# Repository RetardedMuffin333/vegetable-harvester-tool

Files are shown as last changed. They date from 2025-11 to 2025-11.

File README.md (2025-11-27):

# Robotic Tool for Harvesting Stem Vegetables
Electromechanical end-effector tool for gripping and cutting stem vegetables (such as asparagus).  
Designed to be mounted on a delta robot for automated harvesting.

This project was created as part of the **Electro-Mechanical Product Design** course at the University of Ljubljana, Faculty of Electrical Engineering.

The repository includes a complete **mechanical design**, **electronics design**, and **system integration** of the end-effector.

---

## 1. Project Overview

The goal of this project was to design an end-effector capable of:

- Gripping a single stem vegetable from any direction  
- Stabilizing it during cutting  
- Cutting it in a horizontal plane  
- Attaching to a delta parallel robot  
- Staying within strict weight and size limits  

The final design includes a fully developed mechanical concept and a matching custom PCB designed for motor control and system interfacing.

---

## 2. Mechanical Design

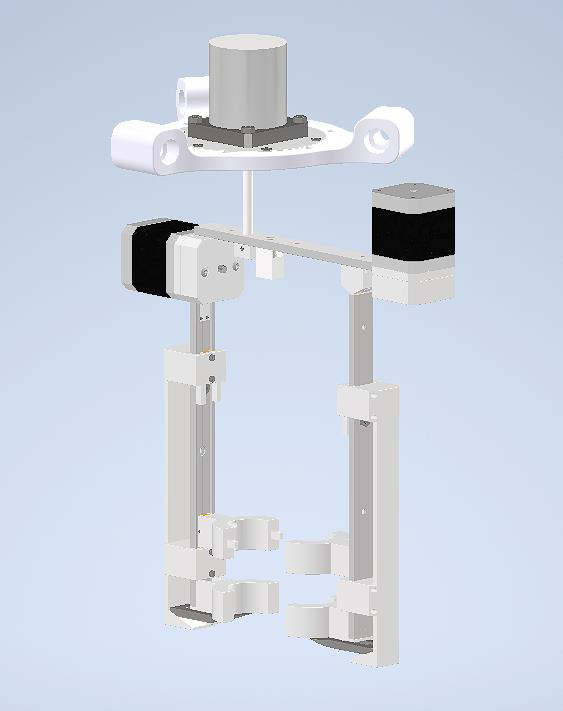
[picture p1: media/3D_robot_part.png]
Mechanical overview


### Key Features
- Four-arm cage gripping mechanism  
- Two fixed arms + two moving arms  
- Belt-driven horizontal and vertical motion  
- Height-triggered cutting mechanism (cams, ramps, springs, sliding blade)  
- Servo motor allowing 360° rotation  
- Designed to avoid unripe vegetables  
- Target mass: **< 700 g**

### Included Files
- Complete 3D CAD model (assemblies and components)  
- Exploded view  
- Mechanism simulation  
- Technical drawings  
- Bill of materials  

All mechanical files are located in:  
`/mechanical/`

---

## 3. Electronics Design

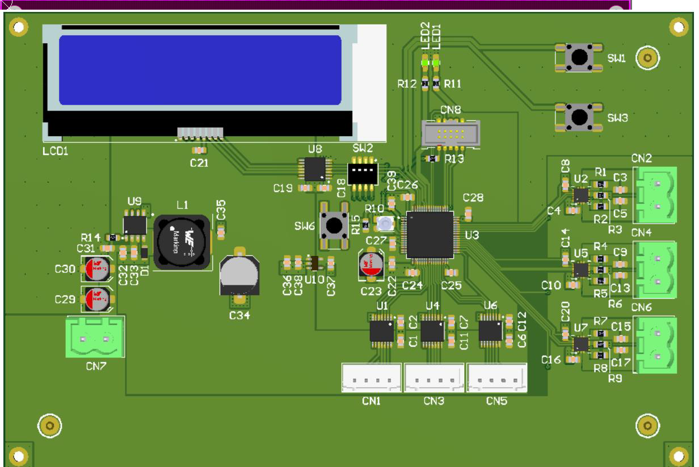
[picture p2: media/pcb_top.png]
PCB top view


### Key Features
- STM32L476RG microcontroller  
- Three MP6619 H-bridge motor drivers  
- 24 V → 5 V DC/DC switching regulator  
- 5 V → 3.3 V linear regulator  
- Level shifter for encoder inputs  
- JTAG programming header  
- Status LEDs, DIP switches, potentiometer, push buttons  
- LCD display interface  
- Custom 2-layer PCB designed in Altium

### Included Files
- Full schematics  
- PCB layout  
- 3D PCB assembly  
- Gerber files  
- Custom component libraries

All electronics files are located in:  
`/electronics/`

---

## 4. Firmware

### Overview
The firmware folder contains **prototype firmware** for the vegetable-harvester end-effector tool.  
The goal of this code is to document and simulate the intended behaviour of the tool without requiring access to the real robot or STM32 hardware.

### Key Features
- Hardware-agnostic state machine architecture  
- PC-friendly stub implementation for testing  
- No external dependencies — pure C11  
- Allows validation of logic and behaviour on any PC  

### Files
- **`tool_controller.c`** — High-level state machine controlling the harvester tool:
  - Opens/closes gripper  
  - Lowers/raises tool  
  - Manages cutting height  
  - Handles emergency-stop  
  - Uses abstract `hw_*` hardware calls (fully hardware-agnostic)  

- **`hw_stub.c`** — PC-friendly stub implementation of the hardware layer:
  - Replaces real STM32 GPIO/PWM/UART with `printf()` simulations  
  - Allows running the full tool cycle on any PC  
  - Useful for validating logic and behaviour  

### Compile & Run (Optional)
```bash
gcc tool_controller.c hw_stub.c -std=c11 -Wall -Wextra -o harvester_test
./harvester_test
```

All firmware files are located in:  
`/firmware/`

---

## 6. Media

Images, renders, videos, mechanism animations, exploded views, and PCB 3D previews.

Stored in:  
`/media/`

---

## 7. Documentation

- Mechanical report (PDF)  
- Electronics report (PDF)  
- Technical drawings (PDF)

Located in:  
`/docs/`

---

## 8. Skills Demonstrated

### Mechanical Engineering
- CAD modeling and assemblies  
- Motion systems and kinematics  
- Mechanism and tool design  
- Component selection  
- Design for constraints (weight, geometry, material limits)

### Electrical Engineering
- Schematic design in Altium  
- PCB layout (routing, grounding, decoupling)  
- Motor driver circuitry  
- Power conversion (DC/DC and LDO)  
- Digital/analog interfacing  

### Systems Engineering
- Integrating mechanical and electronic subsystems  
- Error analysis and optimization  
- Documenting design workflows  
- Understanding system constraints and interactions

---

## 9. Future Improvements

- Reduce overall mass of the tool  
- Optimize motor selection and torque requirements  
- Improve PCB thermal performance  
- Add environmental and proximity sensors  
- Add end-stop switches for better motor homing  
- Integrate a small UPS to preserve state on power loss  

---

## 10. Repository Structure

```
vegetable-harvester-tool/
│
├── mechanical/
├── electronics/
├── firmware/
├── media/
├── docs/
└── README.md
```

---

## 11. Author

**Aljaž Murovec**  
University of Ljubljana — Faculty of Electrical Engineering

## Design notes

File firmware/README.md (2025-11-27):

# Firmware (Prototype)

This folder contains the **prototype firmware** for the vegetable-harvester end-effector tool.  
The goal of this code is to document and simulate the intended behaviour of the tool without requiring access to the real robot or STM32 hardware.

---

## Files

### `tool_controller.c`
High-level state machine controlling the harvester tool:

- Opens gripper  
- Closes gripper  
- Lowers tool to cutting height  
- Raises tool  
- Releases harvested vegetable  
- Monitors emergency-stop  
- Uses abstract `hw_*` hardware calls (no MCU-specific code inside)

The code is fully hardware-agnostic.  
All physical interactions are delegated to the hardware layer.

---

### `hw_stub.c`
A **PC-friendly stub** implementation of the hardware layer.

- Replaces real STM32 GPIO/PWM/UART with `printf()` simulations  
- Allows running the full tool cycle on any PC  
- Useful for validating logic and behaviour  
- No external dependencies — pure C11

Compile & run locally (optional):

```bash
gcc tool_controller.c hw_stub.c -std=c11 -Wall -Wextra -o harvester_test
./harvester_test

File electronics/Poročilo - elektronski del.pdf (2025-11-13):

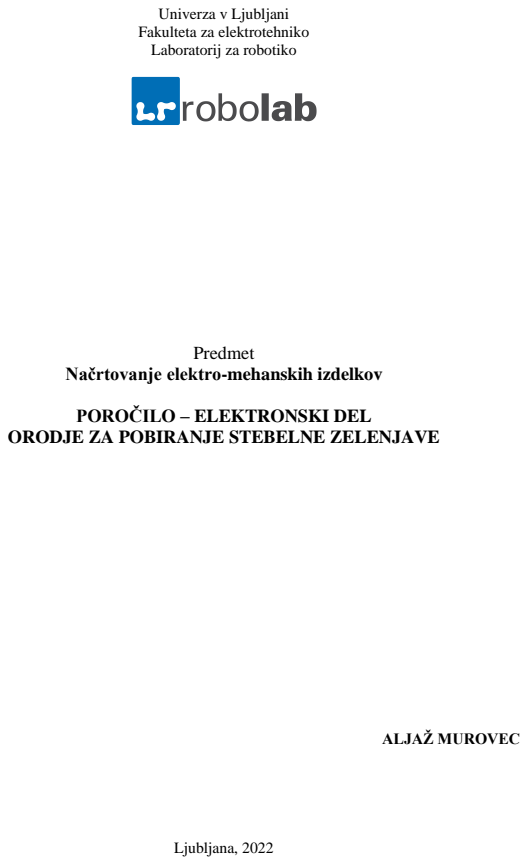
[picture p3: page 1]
Predmet; ALJAŽ MUROVEC; Ljubljana, 2022

Univerza v Ljubljani
Fakulteta za elektrotehniko
Laboratorij za robotiko

Načrtovanje elektro-mehanskih izdelkov

POROČILO – ELEKTRONSKI DEL

ORODJE ZA POBIRANJE STEBELNE ZELENJAVE

# 1.) Predstavitev problema in ideje

Izdelava načrta električnega vezja oz. PCB plošče, ki bo omogočala realizacijo delovanja mehanskega dela pri načrtovanju orodja za pobiranje stebelne zelenjave. Kot osnovo vezja smo vzeli mikrokrmilnik STM32L476RG na katerega je bilo potrebno pripeljati vse ostale komponente, ki bodo skrbele za pravilno delovanje orodja. Za napajanje vezja skrbi 24V baterija, zato je bilo potrebno to napetost zmanjšati, saj določene komponente vezja delujejo na precej manjši napetosti, poleg tega pa poskrbeti tudi za stabilizacijo napetosti. Večji del vezja vsebuje elemente, potrebne za delovanje oz. krmiljenje motorjev, saj ti opravljajo glavno funkcijo orodja. Za to sem potreboval h-mostiče in enkoderje, nato pa sem poleg močnostnih konektorjev in statusnih LED diod, za boljšo uporabniško izkušnjo dodal še LCD zaslon, na kateremu se izpisujejo različne informacije. Za pravilno delovanje vezja je bilo potrebno poskrbeti še za pravilno širino povezav oz. upoštevati tokovne zahteve vezja.

# 2.) Predstavitev elektronskega dela

## 2.1.) Kosovnica

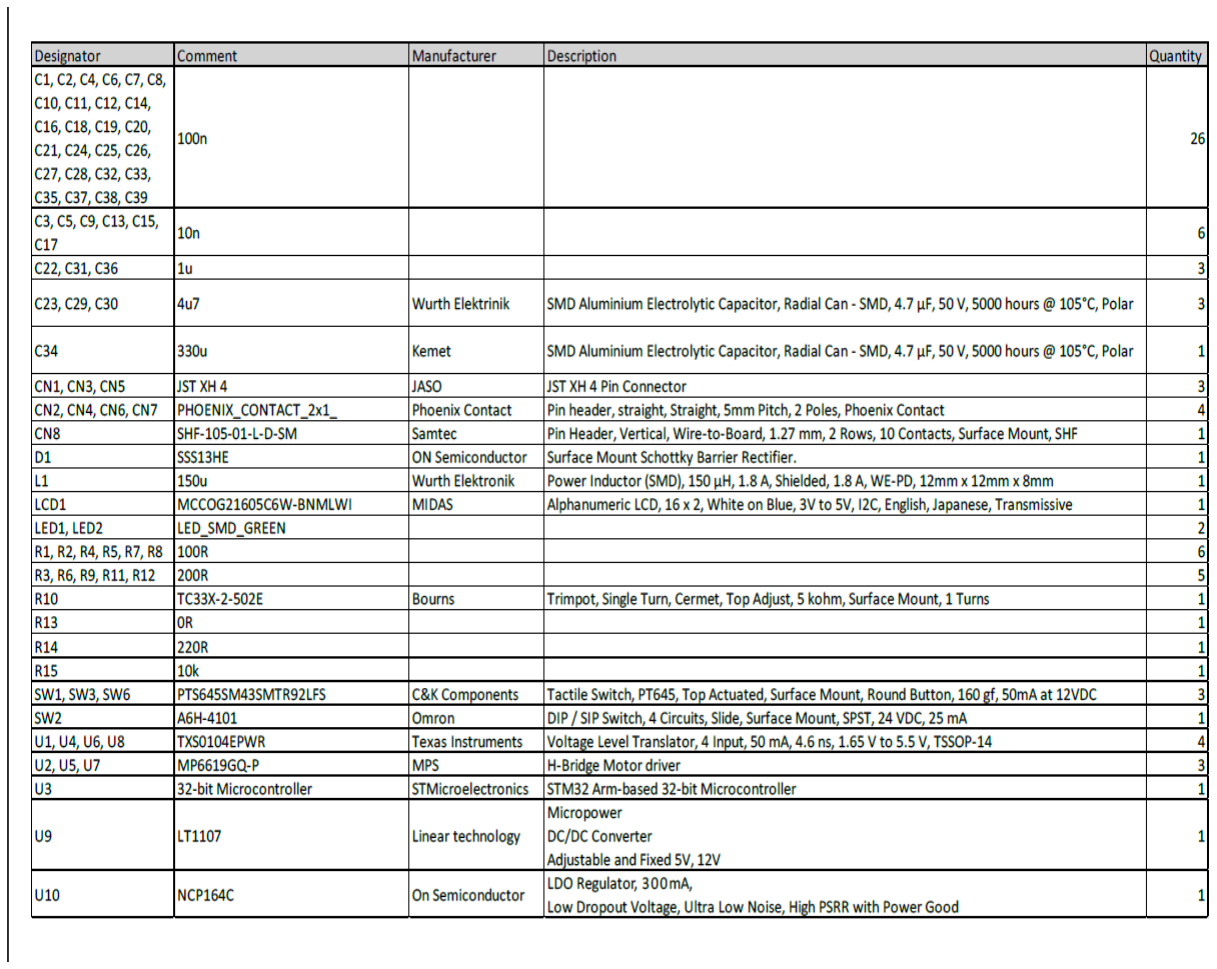
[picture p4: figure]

## 2.2.) Shematski prikaz in razlaga delovanja vezja

- STM32 mikrokontroler
Za mikrokontroler smo vzeli STM32L476RGT. Pinout prikazan na spodnji sliki je vzet iz data sheet, zraven pa je priložena tudi shematika z vsemi povezavami, kot so uporabljene v nadaljevanju.

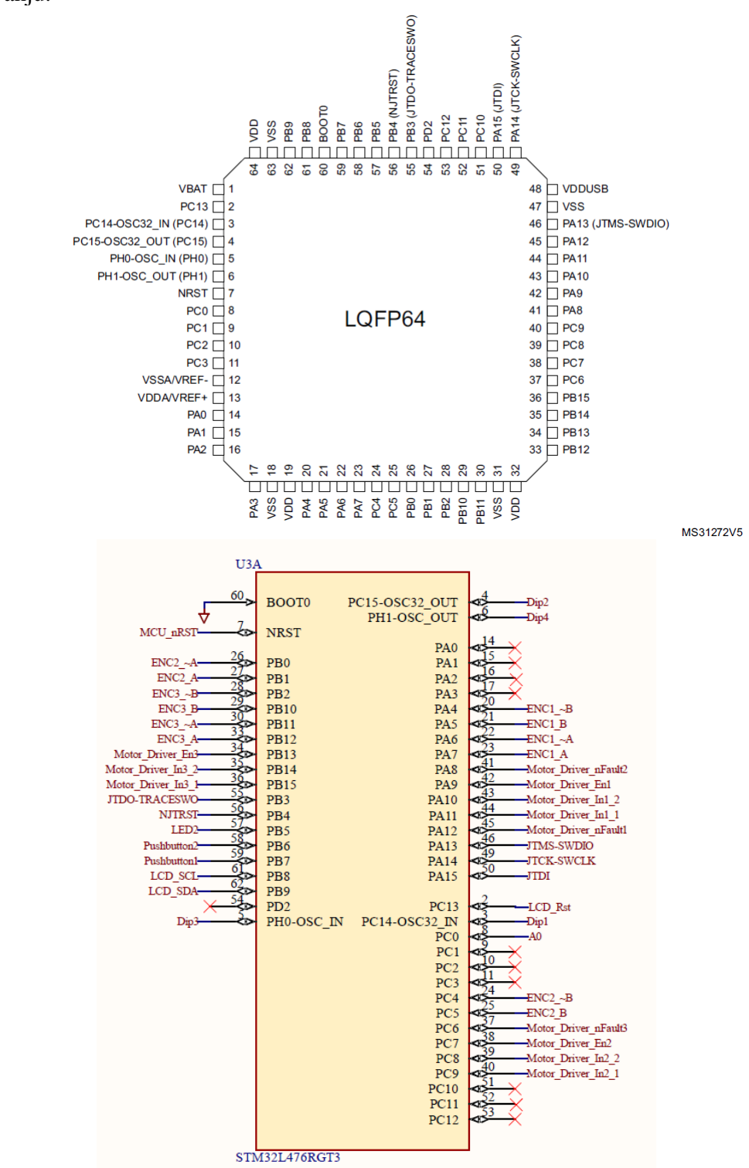
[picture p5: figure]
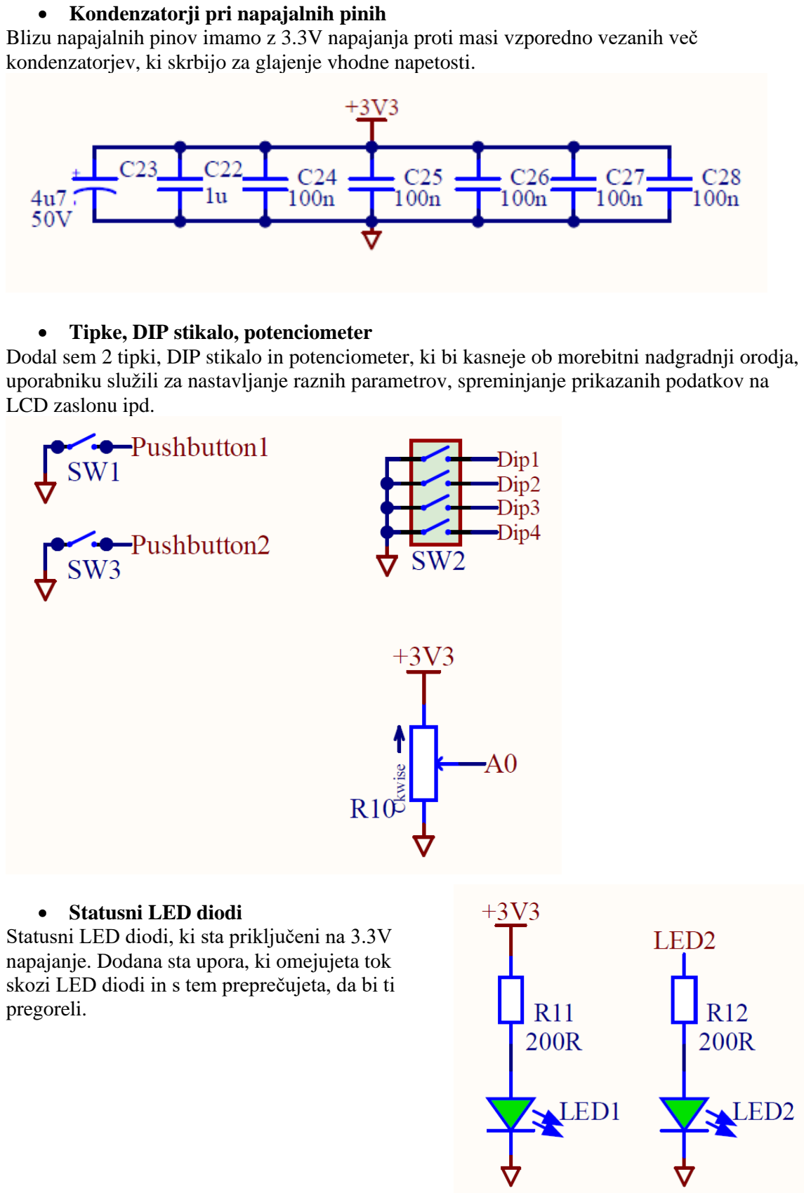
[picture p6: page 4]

- Kondenzatorji pri napajalnih pinih
Blizu napajalnih pinov imamo z 3.3V napajanja proti masi vzporedno vezanih več kondenzatorjev, ki skrbijo za glajenje vhodne napetosti.
- Tipke, DIP stikalo, potenciometer
Dodal sem 2 tipki, DIP stikalo in potenciometer, ki bi kasneje ob morebitni nadgradnji orodja, uporabniku služili za nastavljanje raznih parametrov, spreminjanje prikazanih podatkov na LCD zaslonu ipd.
- Statusni LED diodi
Statusni LED diodi, ki sta priključeni na 3.3V napajanje. Dodana sta upora, ki omejujeta tok skozi LED diodi in s tem preprečujeta, da bi ti pregoreli.

- Level shifter za enkoder

Spodaj uporabljen level shifter oz. translator TXS0104EPWR za enkoder iz 5 V na 3.3 V

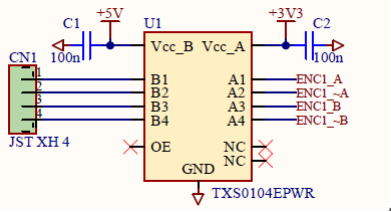
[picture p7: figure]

¸

- H-mostič

V vezju so dodani trije H-mostiči MP6619GQ-P za krmiljenje motorjev, ki so priključeni na konektorje povezane na izhod H-mostiča skupaj z bootstrap upori. Čip je priključen na vhodno napetost 24 V kondenzatorji pa gladijo napetost. Na IN vhodih s pulzno širinsko modulacijo krmilimo motorje.

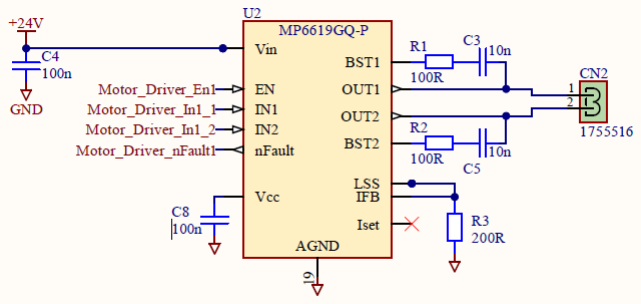
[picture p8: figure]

- DC/DC pretvornik
Uporabil sem DC/DC pretvornik LT1107 za pretvarjanje napetosti iz 24 V na 5 V in linearni napetostni regulator NPC164C za pretvarjanje napetosti iz 5 V na 3.3 V.
Upor na pinu 1 pri LT1107 skrbi za omejevanje toka, Schottky dioda pa je dodana za nižanje napetosti ob preklopu.

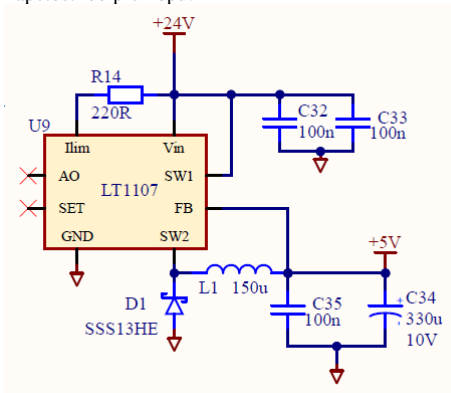
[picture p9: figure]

Linearni napetostni regulator je precej cenejši in enostavnejši za izvedbo, dodani so zgolj kondenzatorji za glajenje napetosti.

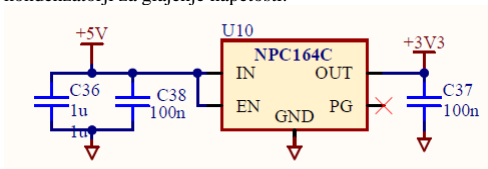
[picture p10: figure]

- JTAG/ST link povezava
JTAG nam omogoča ST link povezavo, za programiranje in debuggiranje mikrokontrolerja.

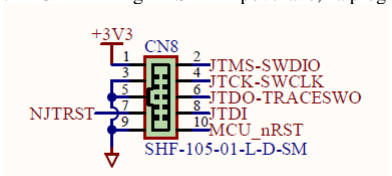
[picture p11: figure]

- LCD display
Za napajalno napetost vzamemo 5 V, ki skrbi tudi za logični del. Na SDA, SCL in RST pine pripeljemo izhod iz level translatorja (3.3 V to 5 V) za translacijo logičnih nivojev oz, napetosti.

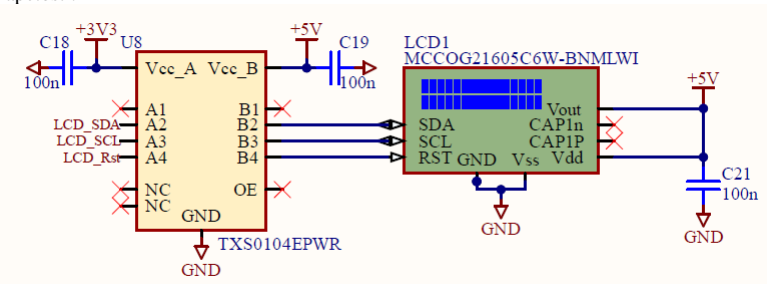
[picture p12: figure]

## 2.3.) Razvoj sheme

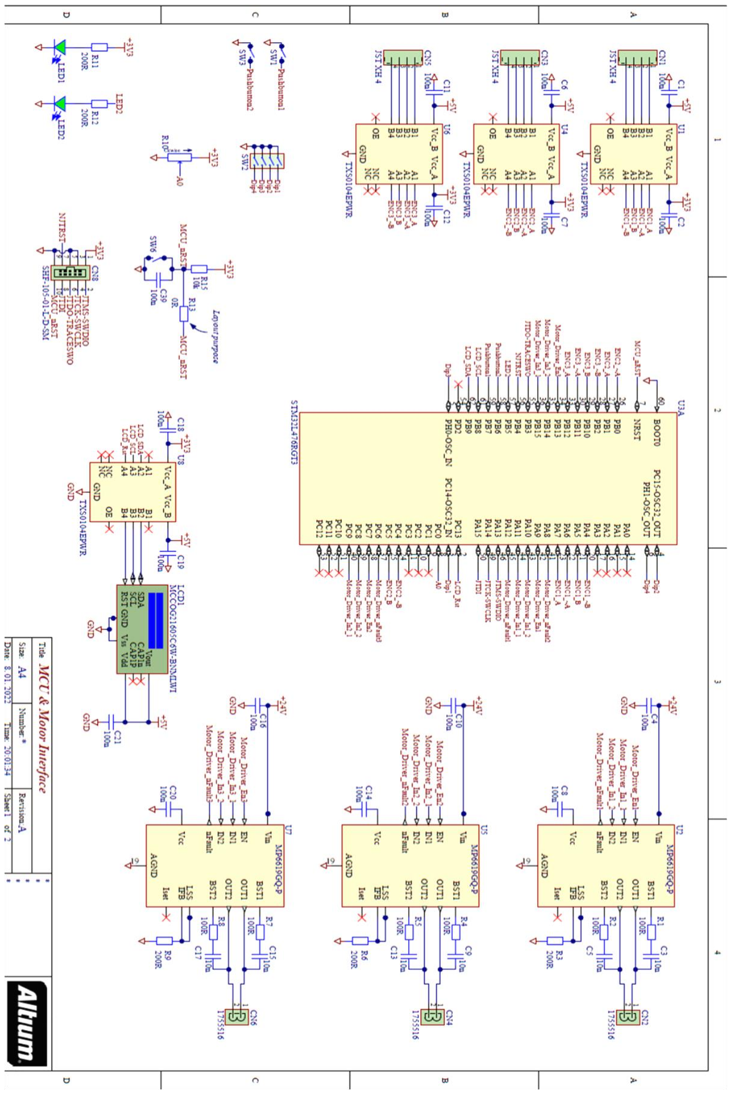
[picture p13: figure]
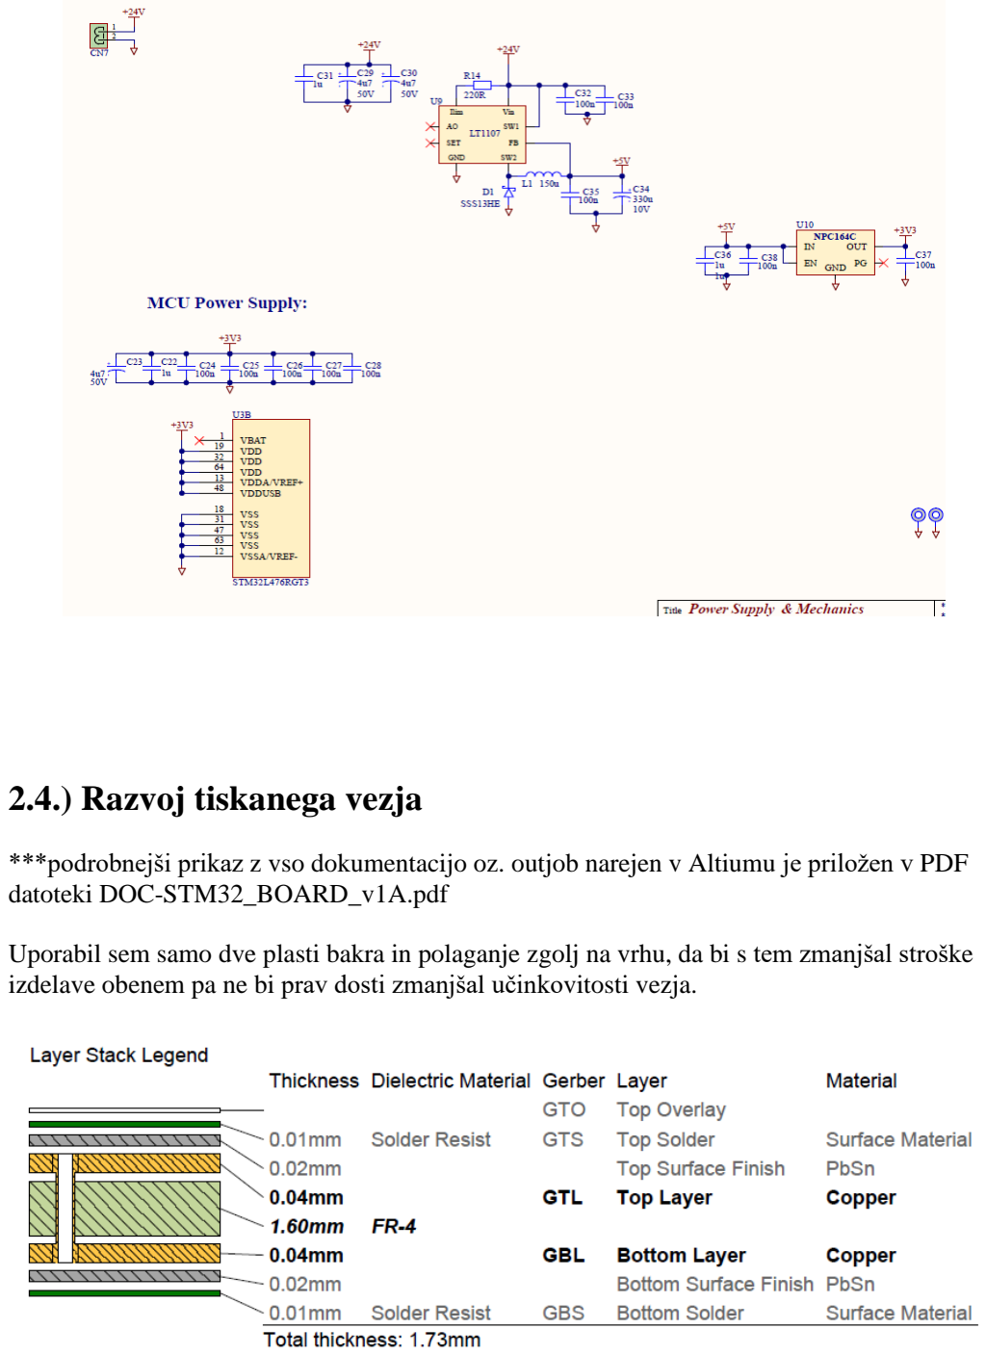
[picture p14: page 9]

## 2.4.) Razvoj tiskanega vezja

***podrobnejši prikaz z vso dokumentacijo oz. outjob narejen v Altiumu je priložen v PDF datoteki DOC-STM32_BOARD_v1A.pdf

Uporabil sem samo dve plasti bakra in polaganje zgolj na vrhu, da bi s tem zmanjšal stroške izdelave obenem pa ne bi prav dosti zmanjšal učinkovitosti vezja.

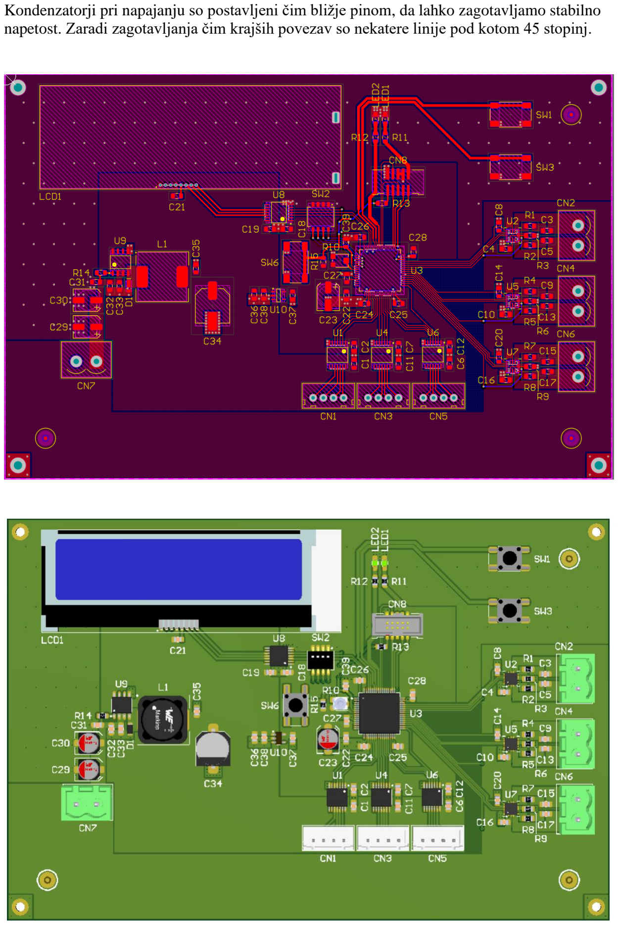
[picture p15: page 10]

Kondenzatorji pri napajanju so postavljeni čim bližje pinom, da lahko zagotavljamo stabilno napetost. Zaradi zagotavljanja čim krajših povezav so nekatere linije pod kotom 45 stopinj.

## 2.5.) Vključitev 3D modela v mehanski sestav

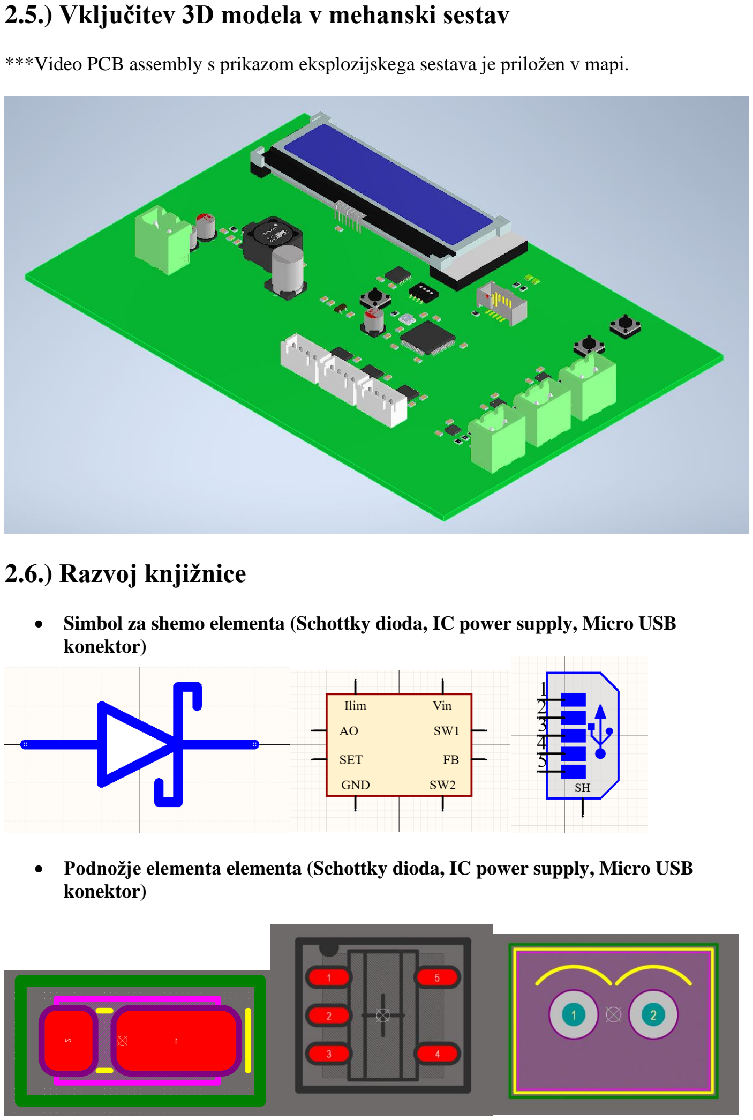
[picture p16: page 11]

***Video PCB assembly s prikazom eksplozijskega sestava je priložen v mapi.

## 2.6.) Razvoj knjižnice

- Simbol za shemo elementa (Schottky dioda, IC power supply, Micro USB konektor)
- Podnožje elementa elementa (Schottky dioda, IC power supply, Micro USB konektor)

- 3D model elementa (Schottky dioda, IC power supply, Micro USB konektor)

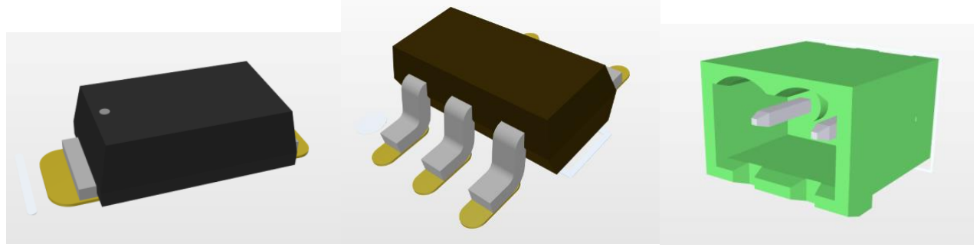
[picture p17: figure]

*** Knjižnice so posebej priložene v mapi AltiumLibraries

# 3.) Predstavitev aktualnih problemov pri izdelku ter predlagane rešitve

Najprej bi še dodatno preučil izbiro trenutnih komponent in jih po potrebi zamenjal z bolj optimalnimi glede na potrebe orodja. Prav tako se nisem preveč posvečal termalnim potrebam vezja.
Kar se tiče nadgradnje, bi v vezje vključil več senzorjev; od čisto preprostih senzorjev vlage, temperature ipd., ki bi uporabniku omogočali spremljanje delovnega okolja robota pa do senzorjev razdalje, laserski senzor (prekinjen žarek bi pomenil, da je špargelj med obema rokama, kar bi sprožilo začetek rezanja), dodal pa bi lahko tudi končna stikala in s tem poenostavil delovanje motorjev.
Smiselna bi bila tudi uporaba UPS, s čimer bi lahko preprečili izgubo podatkov pridobljenih iz senzorjev in podatke o položaju motorjev, v primeru izgube glavnega napajanja.

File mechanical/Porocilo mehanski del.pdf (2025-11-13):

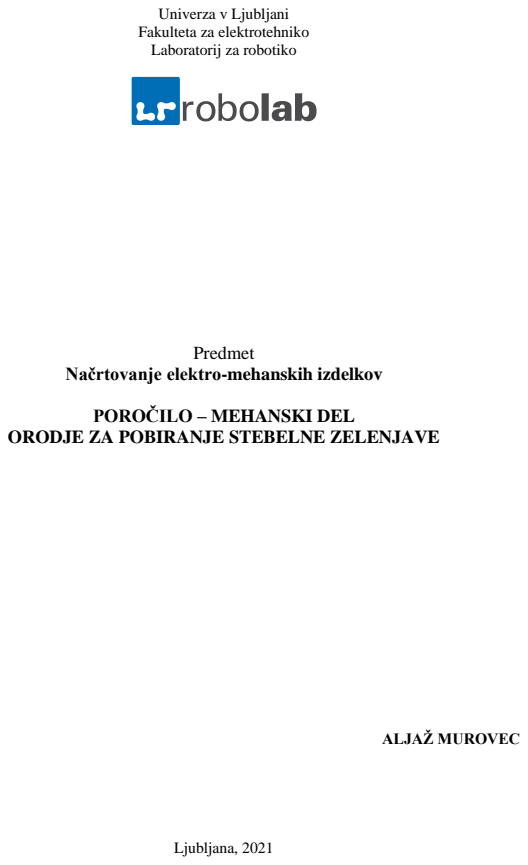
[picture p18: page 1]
Predmet; ALJAŽ MUROVEC; Ljubljana, 2021

Univerza v Ljubljani
Fakulteta za elektrotehniko
Laboratorij za robotiko

Načrtovanje elektro-mehanskih izdelkov

POROČILO – MEHANSKI DEL

ORODJE ZA POBIRANJE STEBELNE ZELENJAVE

## 1.Predstavitev problema

Izdelava mehanskega načrta orodja za pobiranje stebelne zelenjave, ki nam omogoča prijemanje in rezanje stebelne zelenjave. Poleg tega mora zadostovati nekaterim zahtevam in sicer rezati se mora v horizontalni ravnini ter omogočiti prijemanje in rezanje iz katere koli strani. S tem naj se omogoči tudi izogibanje rastlinam, ki še niso dovolj velike za pobiranje. Masa orodja ne sme preseči 700g, nameščena pa naj bo na vrh delta paralelnega robota. Pri načrtovanju je bilo potrebno upoštevati tudi lastnosti same zelenjave, npr. višina, premer, trdota, smer rasti…

## 2.Predstavitev ideje

Moja prvotna ideja je bila, da bi namesto običajnega prijemala imel kletko, kar bi omogočalo pobiranje z vrha in tako tudi izogibanje rastlin. Zaradi morebitne ukrivljene rasti špargljev, tega ni bilo mogoče optimalno izvesti, zato sem moral idejo malo spremeniti.
Namesto prijemanja z vrha, sem se odločil za prijemanje pri tleh od strani. Iz dveh smeri bi špargelj v kletko ujele 4 polkrožne roke. Od tega, sta 2 fiksni, drugi 2 pa premikajoči. Ti bi se, ko bi enkrat objeli špargelj in ustvarili kletko, premaknili višje in s tem preprečili da se špargelj zaradi svoje višine ne prevrne iz kletke. Hkrati, bi ta roka na določeni višini zadela ob mehanizem na vodilu, ki skrbi za premikanje rezila in sprožila zapiranje rezil iz ene in druge strani. Ko je špargelj odrezan, ostane rezilo zaprto dokler se orodje ne premakne nad posodo za shranjevanje pobranih špargljev, nato se rezilo spet odpre, da špargelj pade v posodo, roke pa se spet premaknejo v začetno pozicijo. Za gibanje bi skrbeli 3 motorji, 1 za vertikalno premikanje rok s pomočjo jermena, 1 za horizontalno premikanje celotnega vodila, prav tako s pomočjo jermena in motor za rotacijo celotnega orodja, nameščen na nastavek za delta paralelnega robota.

## 3.Predstavitev mehanskega dela

## 3.1. Kosovnica

2X kompresijska vzmet:
- notranji premer: 5mm
- dolžina pod max obremenitvijo: 15mm
- dolžina brez obremenitve: 31mm

3X kompresijska vzmet:
- zuananji premer: 5,5mm
- dolžina pod max obremenitvijo: 4mm
- dolžina brez obremenitve: 6,3mm

2X zobati jermen:
- širina: 6mm
-dolžina: 45mm (1x), 25mm (1x)

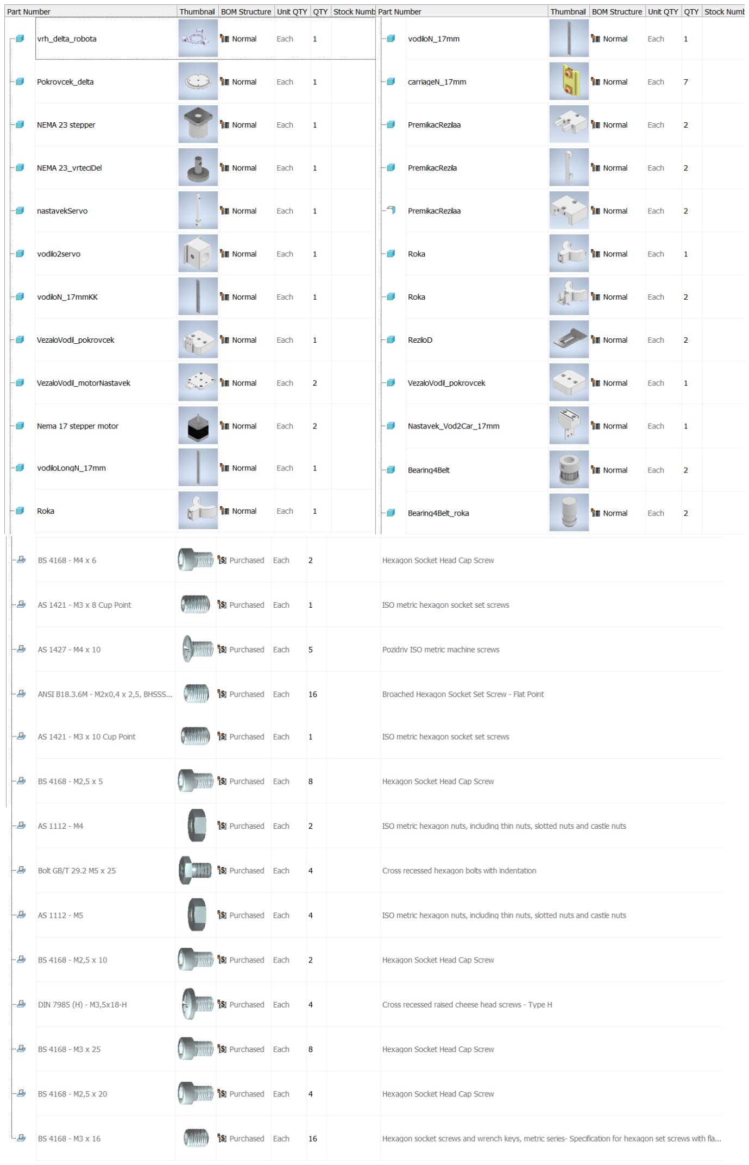
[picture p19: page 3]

## 3.2. CAD model celotnega mehanizma

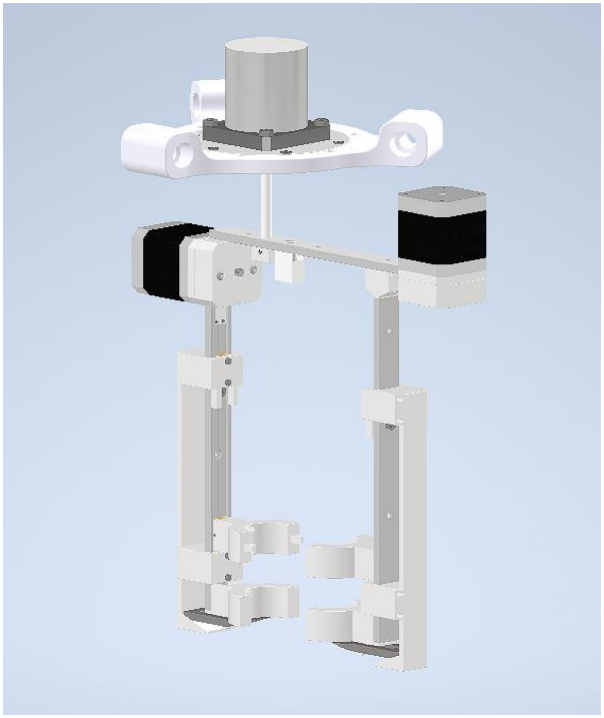
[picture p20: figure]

*** Datoteka s celotnim 3D prikazom je priložena v mapi (AssemblyFINAL v .iam formatu ali v .pdf formatu. Priložena sta tudi posnetka simulacije delovanja in eksplozijskega sestava.

## 3.3. Posamezni mehanski sklopi z ustreznimi opisi

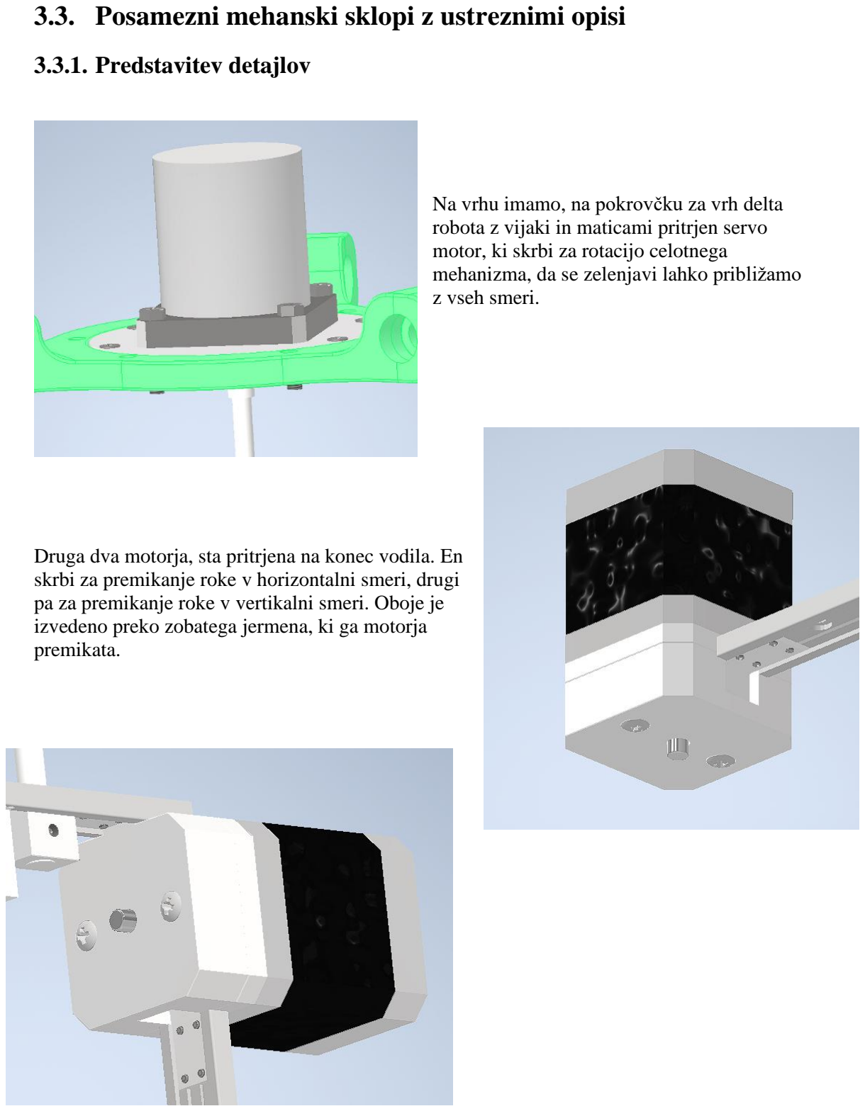
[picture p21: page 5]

### 3.3.1. Predstavitev detajlov

Na vrhu imamo, na pokrovčku za vrh delta robota z vijaki in maticami pritrjen servo motor, ki skrbi za rotacijo celotnega mehanizma, da se zelenjavi lahko približamo z vseh smeri.

Druga dva motorja, sta pritrjena na konec vodila. En skrbi za premikanje roke v horizontalni smeri, drugi pa za premikanje roke v vertikalni smeri. Oboje je izvedeno preko zobatega jermena, ki ga motorja premikata.

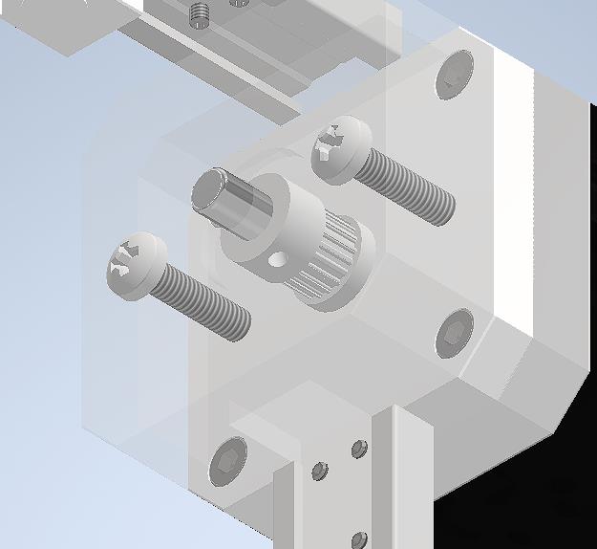
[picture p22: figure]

Na pogonsko gred motorja je s ''set'' vijakom pritrjen osni nastavek z zobnikom, ki skrbi da se jermen premika, ko se motor z nastavkom vrti.

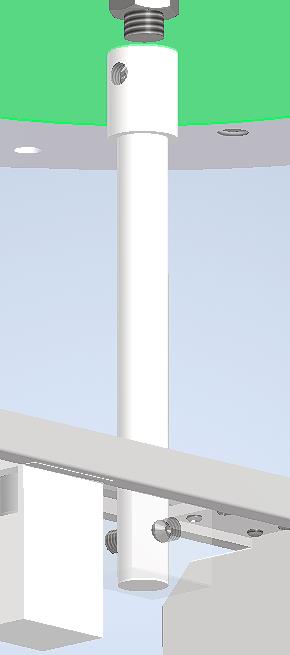
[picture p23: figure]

Gred, ki je s ''set'' vijakom pritrjena v luknjo na pogonski gredi motorja, prenaša rotacijo pogonske gredi na celotni mehanizem. Ta je na gred povezan preko nastavka, ki se poveže s horizontalnim vodilom.

Na sliki je prikazan mehanizem, ki skrbi za premikanje rezila. Z vertikalnim vodilom je na voziček na vodilu prosto povezan prek nastavka. Na vrhu sloni na vijaku ki je pritrjen na vodilo, ki skrbi da mehanizem stoji na pravi višini.

Malo nižje smo na enak način dodali še podporo celotnemu kosu ki porazdeli sile in navore, ki delujejo nanj.

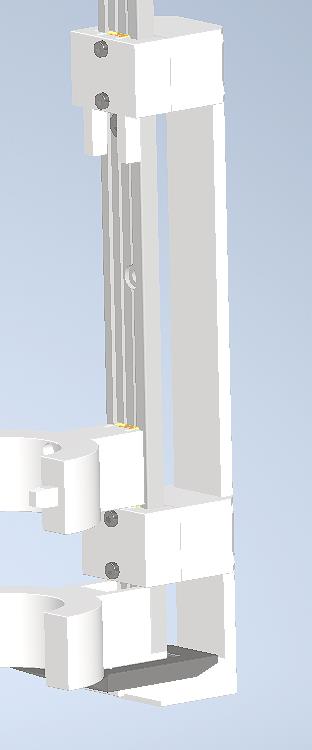
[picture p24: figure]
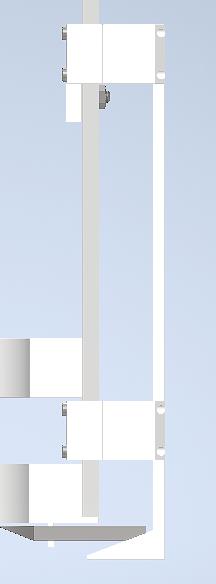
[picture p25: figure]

Na zgornjem nastavku imamo 2 zoba, ki skrbita da se mehanizem premakne za ravno pravšnjo višino, ko nastavek premakne roka, da se rezilo pomakne točno do sredine stebla.

Čisto spodaj je glavni del mehanizma, ki skrbi, da se rezilo premakne. Klančina se stika z rezilom, to pa se ob dvigu mehanizma, ko ga premakne roka pomakne naprej oz. zapre.

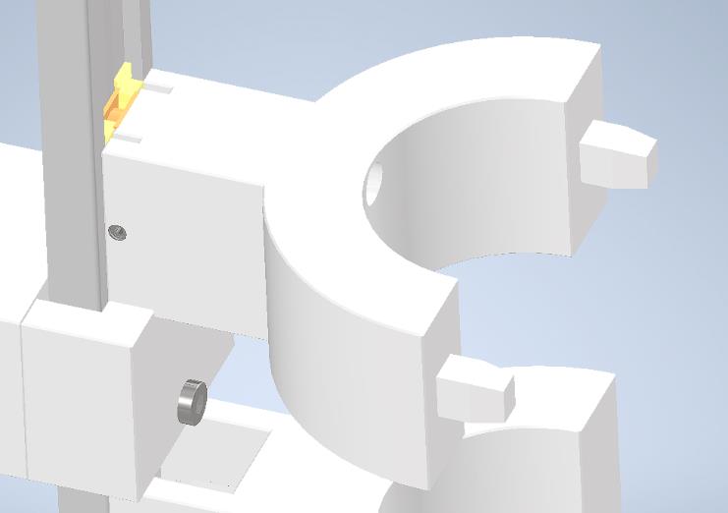
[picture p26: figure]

''Moška'' roka je z vijaki povezana na voziček na vodilu, skozi njo pa gresta 2 odprtini za zobati jermen.
Na jermen se roka prime tako, da z vijakom stisnemo nazobčan košček, ki se tako ''ujame'' v zobati jermen, posledica česar je premik roke ob vrtenju motorja.


V lukniji na ''ženski roki'', padeta izrastka na koncu ''moške roke'' tako da se ob premiku le-te, hkrati z njo premakne tudi ta roka.

To premikanje obeh rok, v vertikalni smeri skrbi tudi za premikanje mehanizma za rezila. Roka se namreč dviga in ko zadane v zob mehanizma se začne dvigati še ta, posledično pa se premakne tudi rezilo. Ustavi se ko trči ob vijak, ki prepreči nadaljnje premikanje.


Premikanje rezila sem opisal že v prejšnjem delu razložiti pa je potrebno še, kako se rezilo vrne v začetni položaj.
Ko se mehanizem spusti nazaj v začetno lego se sprosti tudi kompresijska vzmet, ki je nataknjena na valjna izrastka iz rezila in roke. Vzmet tako potisne rezilo nazaj do stene roba mehanizma. Poleg tega, da rezilo sloni na klančini mehanizma, ima še eno podporo ki izhaja iz spodnje roke.

## 3.4. Tehniška risba


*** Tehnična slika boljše kakovosti v .pdf formatu, se nahaja v mapi.

## 4. Predstavitev aktualnih problemov pri izdelku ter predlagane rešitve

-Moj cilj je bil, da bi ta izdelek naredil na malce drugačen od ostalih, že videnih rešitev v prejšnjih letih. Posledično je celotna zadeva precej večja od ostalih, tako da bi v prihodnosti optimiziral velikost konstrukcije.

-Poleg tega je za problem s težo krivo tudi število motorjev, zato bi moral najti način kako zadevo rekonstruirati, da se kakšnega znebim. Veliko prednosti vidim v optimizaciji izbire motorjev. Tu bi moral preračunati in analizirati vse navore in sile, ki delujejo na orodje med njegovo uporabo ter se na podlagi rezultatov odločiti za najbolj optimalnega.

-Optimizacija sestava bi lahko šla tudi v smeri izbire še več standardnih komponent, ki bi poenostavile in pocenile izdelavo.

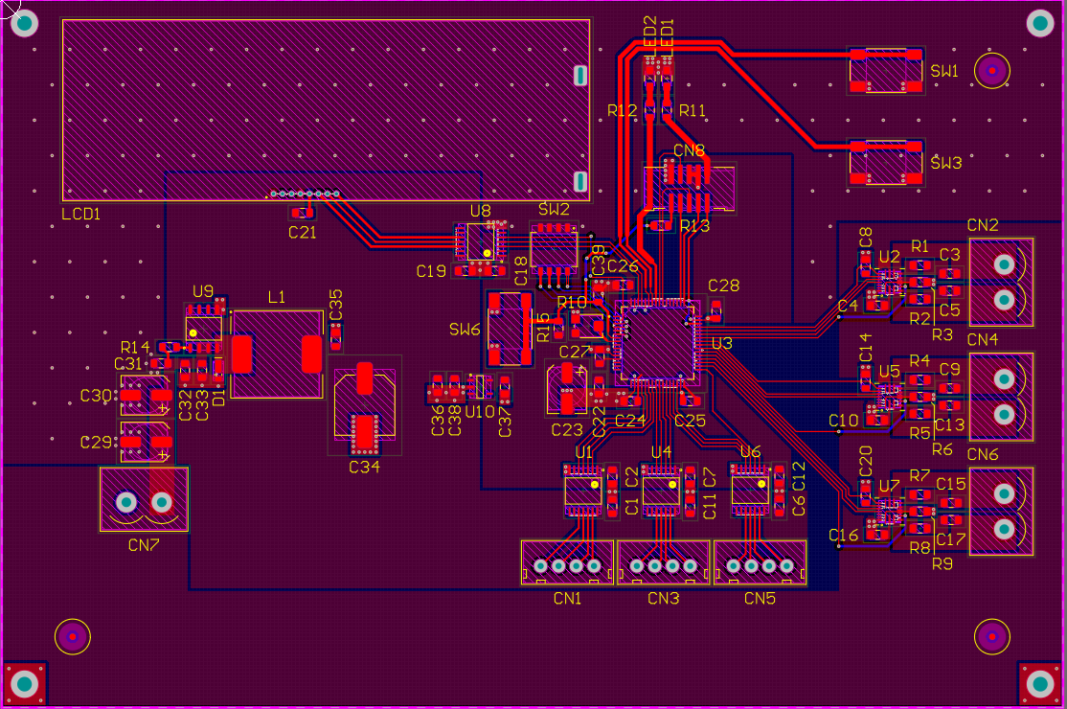
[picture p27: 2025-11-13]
media/pcb_bot.png

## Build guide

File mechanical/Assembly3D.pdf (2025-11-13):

setPageBoxes("Crop", 0, 0, [0,2000,2000,0]);

# TITLE PART NO REVISION DESIGNER ENGINEER NOTES

THE INFORMATION AND/OR MATERIAL IN THIS DOCUMENT IS THE PROPERTY OF AND RESTRICTED INFORMATION AND/OR MATERIAL OF THE AUTHOR. THIS INFORMATION MAY NOT BE USED, REPRODUCED, PUBLISHED OR DISCLOSED TO OTHERS WITHOUT WRITTEN AUTHORIZATION. IT IS TO BE USED ONLY FOR MANUFACTURING ITEMS SPECIFIED WITHIN THE DOCUMENT.

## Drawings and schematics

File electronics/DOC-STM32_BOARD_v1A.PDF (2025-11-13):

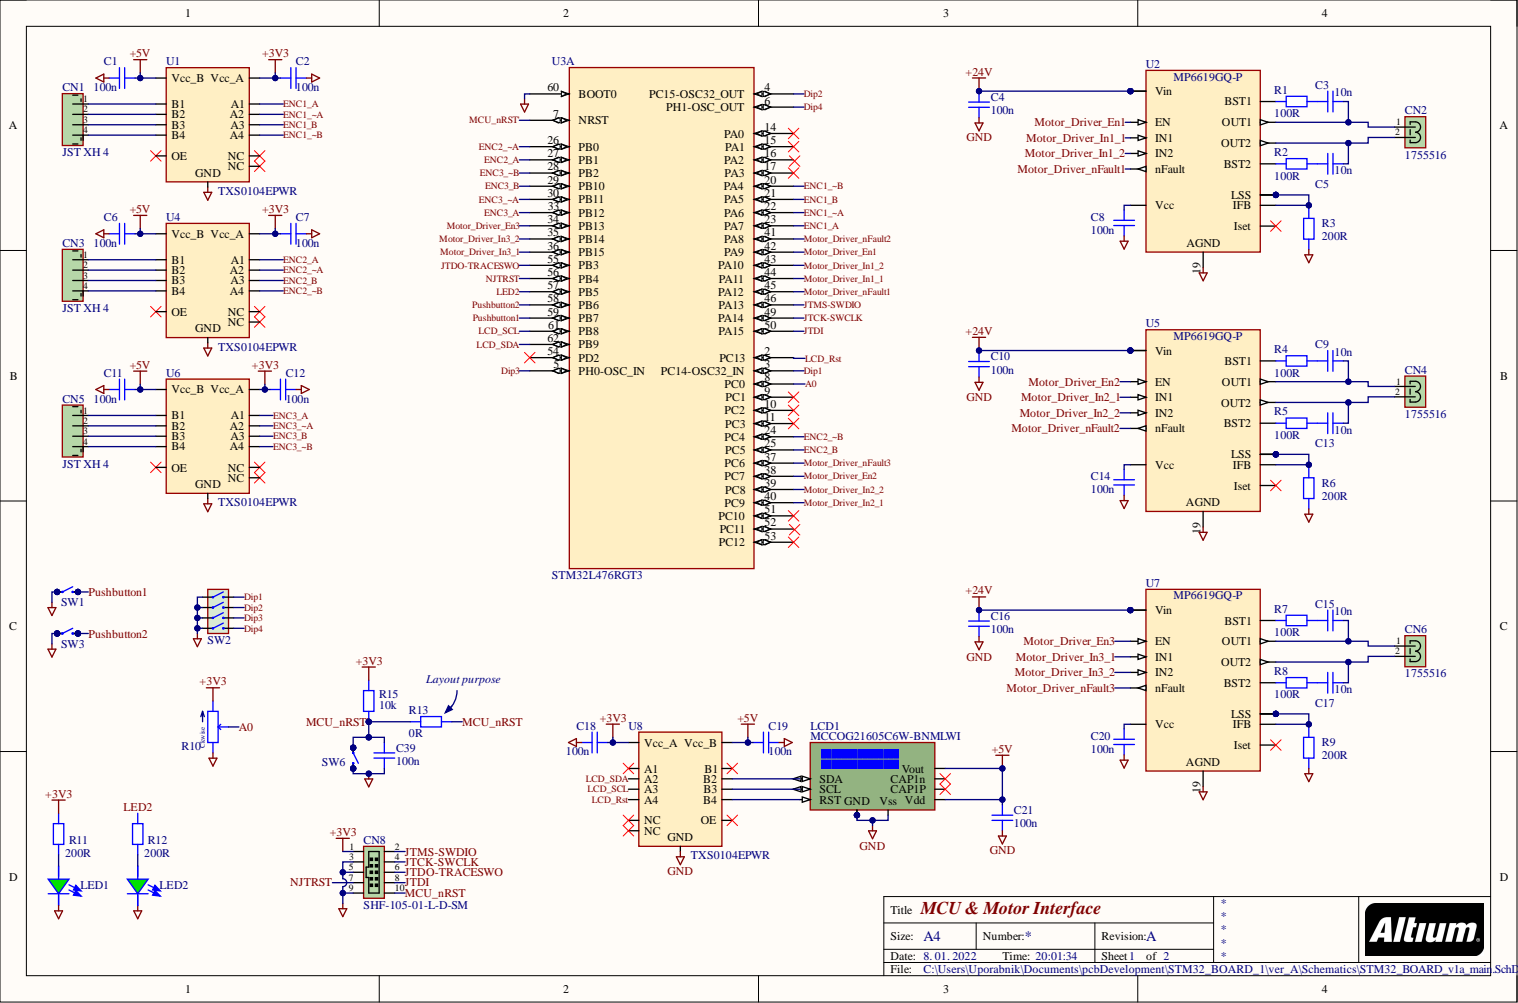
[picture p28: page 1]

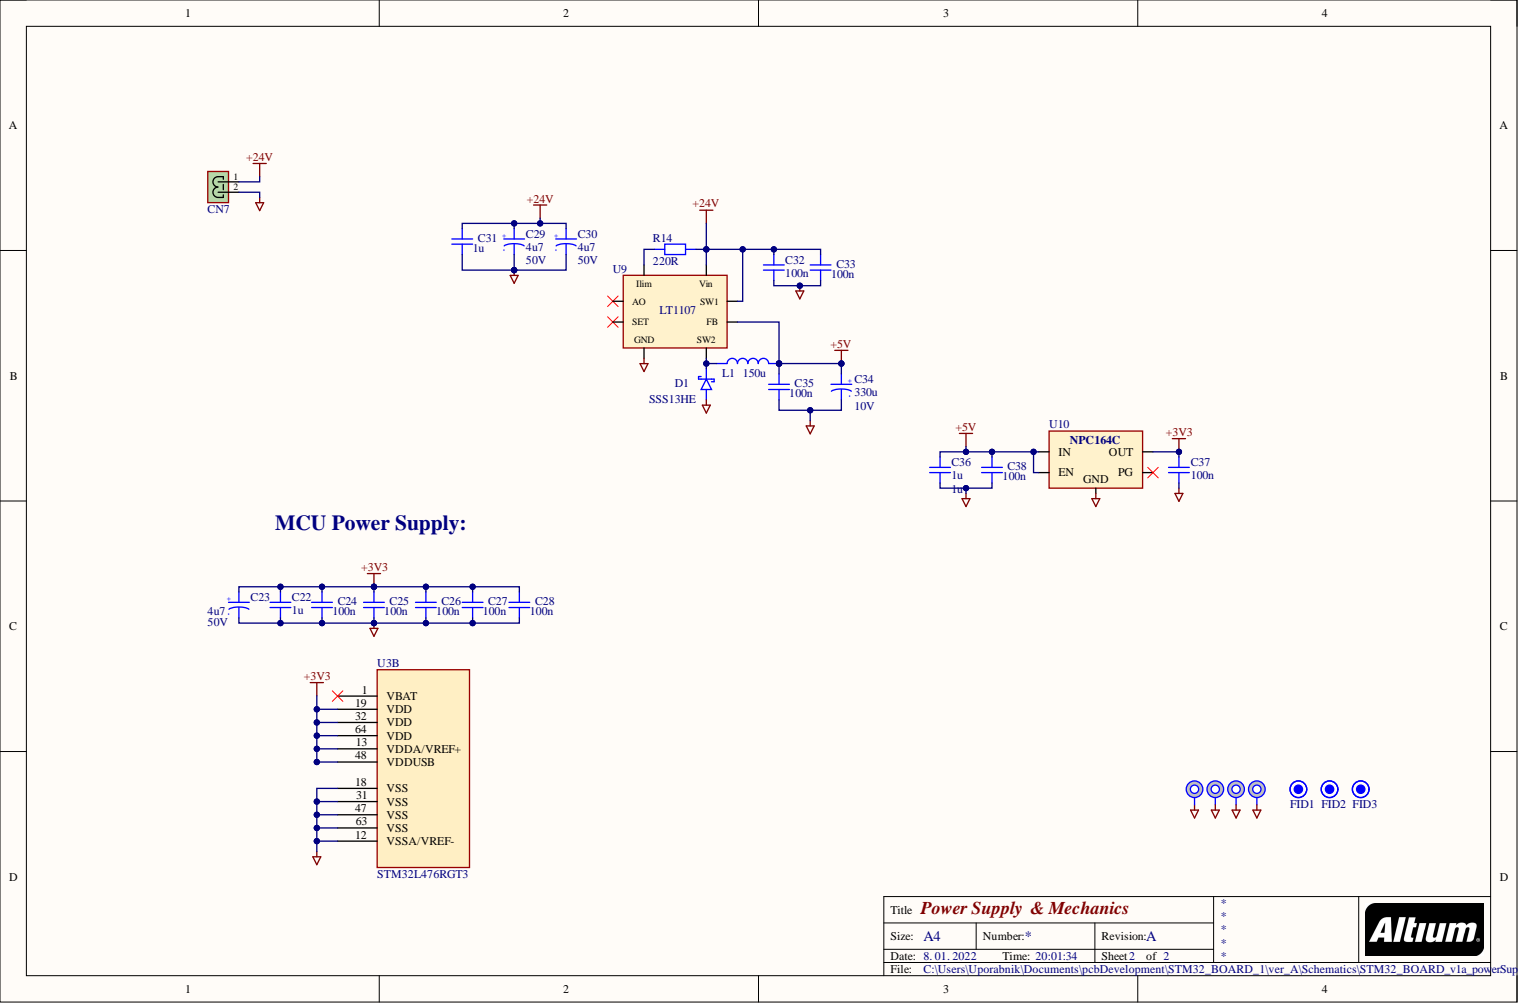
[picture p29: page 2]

C:\Users\Uporabnik\Documents\pcbDevelopment\STM32_BOARD_1\ver_A\Schematics\STM32_BOARD_v1a_powerSupply.SchDoc

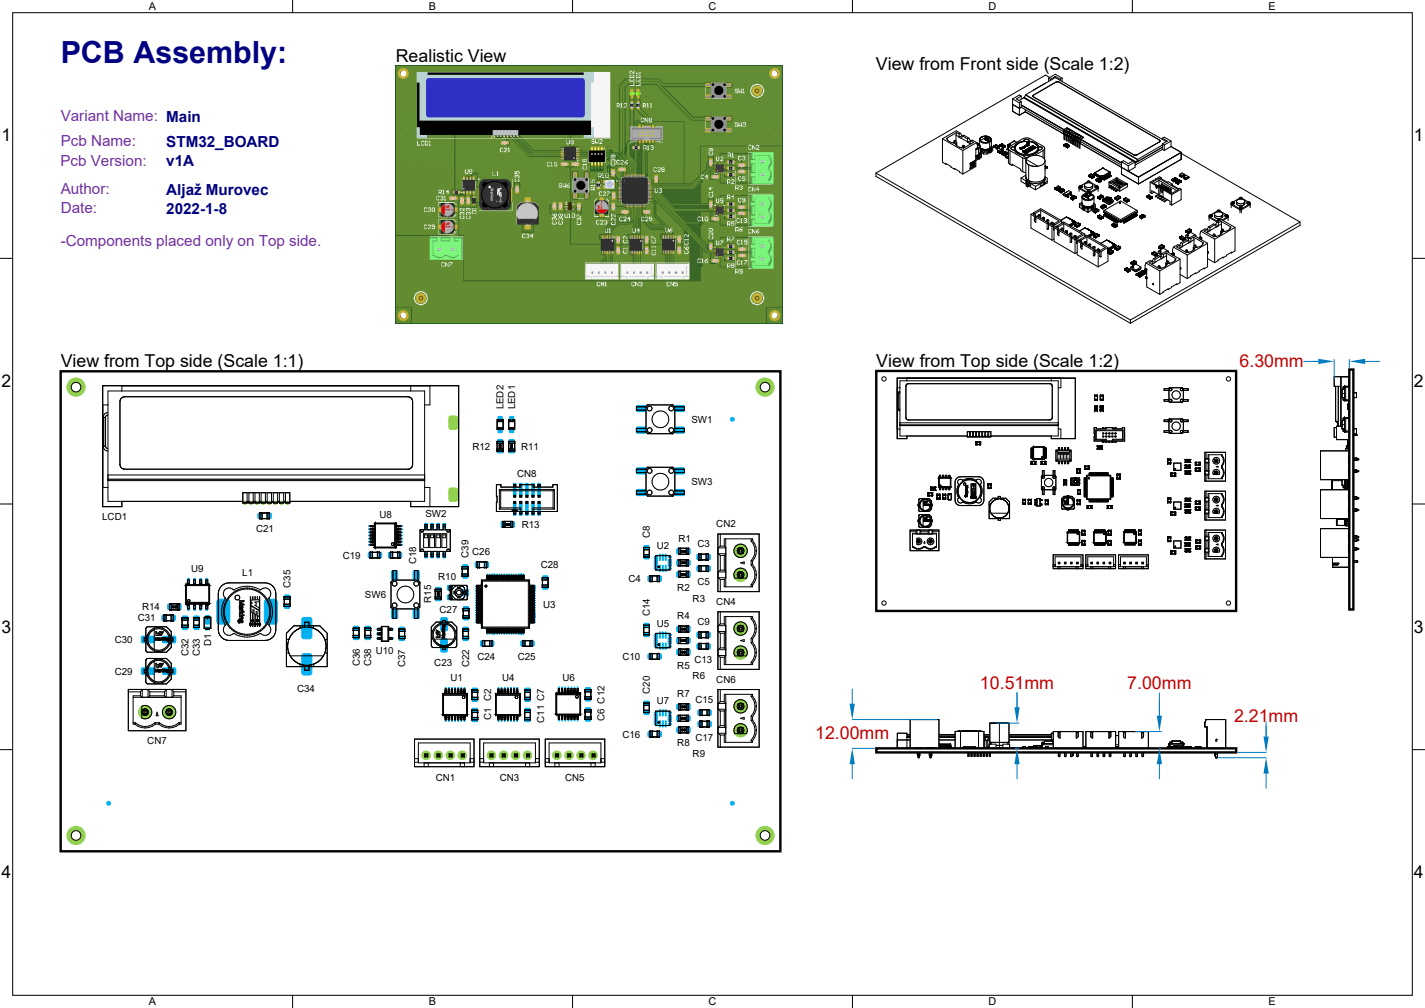
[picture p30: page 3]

View from Front side (Scale 1:2) Realistic View

-Components placed only on Top side.

View from Top side (Scale 1:1)

View from Top side (Scale 1:2)

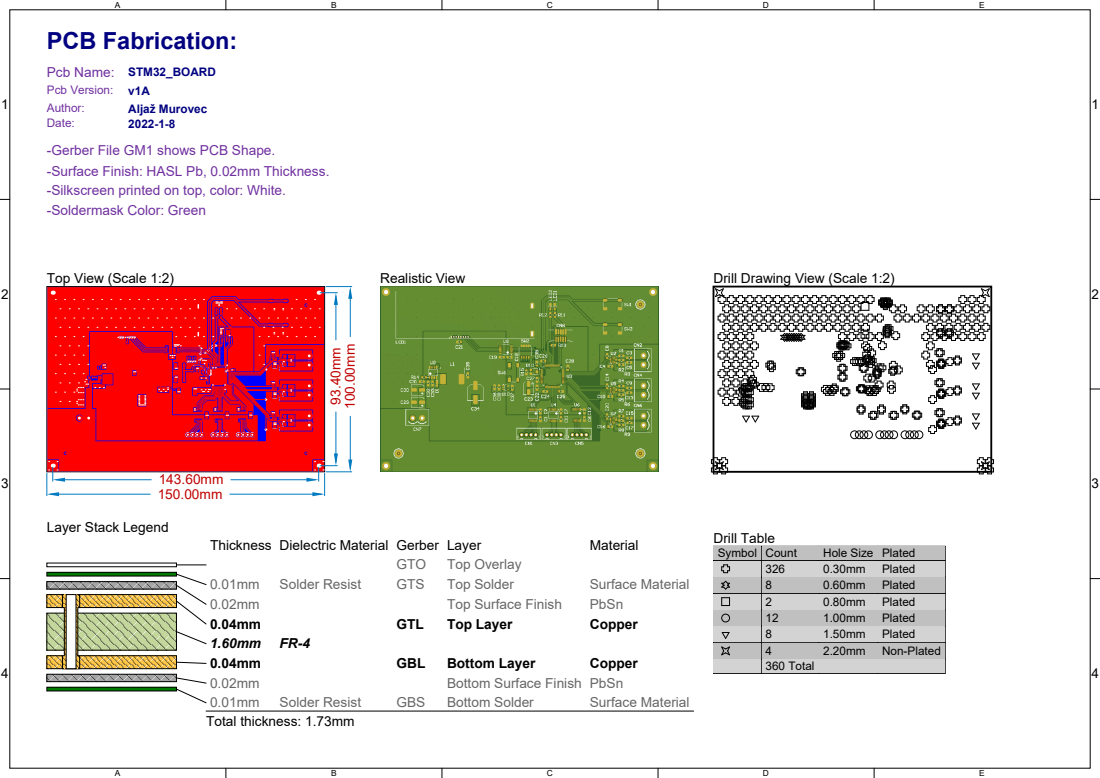
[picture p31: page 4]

Pcb Name: STM32_BOARD
Pcb Version: v1A
-Gerber File GM1 shows PCB Shape.
-Surface Finish: HASL Pb, 0.02mm Thickness.
-Silkscreen printed on top, color: White.
-Soldermask Color: Green

Symbol | Count | Hole Size | Plated

326 | 0.30mm | Plated
8 | 0.60mm | Plated
2 | 0.80mm | Plated
12 | 1.00mm | Plated
8 | 1.50mm | Plated
4 | 2.20mm | Non-Plated
360 Total

Designator | Comment | Manufacturer | Description | Quantity
C1, C2, C4, C6, C7, C8, C10, C11, C12, C14, C16, C18, C19, C20, C21, C24, C25, C26, C27, C28, C32, C33, C35, C37, C38, C39 | 100n | | | 26
C3, C5, C9, C13, C15, C17 | 10n | | | 6
C22, C31, C36 | 1u | | | 3
C23, C29, C30 | 4u7 | Wurth Elektrinik | SMD Aluminium Electrolytic Capacitor, Radial Can - SMD, 4.7 µF, 50 V, 5000 hours @ 105°C, Polar | 3
C34 | 330u | Kemet | SMD Aluminium Electrolytic Capacitor, Radial Can - SMD, 4.7 µF, 50 V, 5000 hours @ 105°C, Polar | 1
CN1, CN3, CN5 | JST XH 4 | JASO | JST XH 4 Pin Connector | 3
CN2, CN4, CN6, CN7 | PHOENIX_CONTACT_2x1_ | Phoenix Contact | Pin header, straight, Straight, 5mm Pitch, 2 Poles, Phoenix Contact | 4
CN8 | SHF-105-01-L-D-SM | Samtec | Pin Header, Vertical, Wire-to-Board, 1.27 mm, 2 Rows, 10 Contacts, Surface Mount, SHF | 1
D1 | SSS13HE | ON Semiconductor | Surface Mount Schottky Barrier Rectifier. | 1
L1 | 150u | Wurth Elektronik | Power Inductor (SMD), 150 µH, 1.8 A, Shielded, 1.8 A, WE-PD, 12mm x 12mm x 8mm | 1
LCD1 | MCCOG21605C6W-BNMLWI | MIDAS | Alphanumeric LCD, 16 x 2, White on Blue, 3V to 5V, I2C, English, Japanese, Transmissive | 1
LED1, LED2 | LED_SMD_GREEN | | | 2
R1, R2, R4, R5, R7, R8 | 100R | | | 6
R3, R6, R9, R11, R12 | 200R | | | 5
R10 | TC33X-2-502E | Bourns | Trimpot, Single Turn, Cermet, Top Adjust, 5 kohm, Surface Mount, 1 Turns | 1
R13 | 0R | | | 1
R14 | 220R | | | 1
R15 | 10k | | | 1
SW1, SW3, SW6 | PTS645SM43SMTR92LFS | C&K Components | Tactile Switch, PT645, Top Actuated, Surface Mount, Round Button, 160 gf, 50mA at 12VDC | 3
SW2 | A6H-4101 | Omron | DIP / SIP Switch, 4 Circuits, Slide, Surface Mount, SPST, 24 VDC, 25 mA | 1
U1, U4, U6, U8 | TXS0104EPWR | Texas Instruments | Voltage Level Translator, 4 Input, 50 mA, 4.6 ns, 1.65 V to 5.5 V, TSSOP-14 | 4
U2, U5, U7 | MP6619GQ-P | MPS | H-Bridge Motor driver | 3
U3 | 32-bit Microcontroller | STMicroelectronics | STM32 Arm-based 32-bit Microcontroller | 1
U9 | LT1107 | Linear technology | Micropower DC/DC Converter Adjustable and Fixed 5V, 12V | 1
U10 | NCP164C | On Semiconductor | LDO Regulator, 300mA, Low Dropout Voltage, Ultra Low Noise, High PSRR with Power Good | 1

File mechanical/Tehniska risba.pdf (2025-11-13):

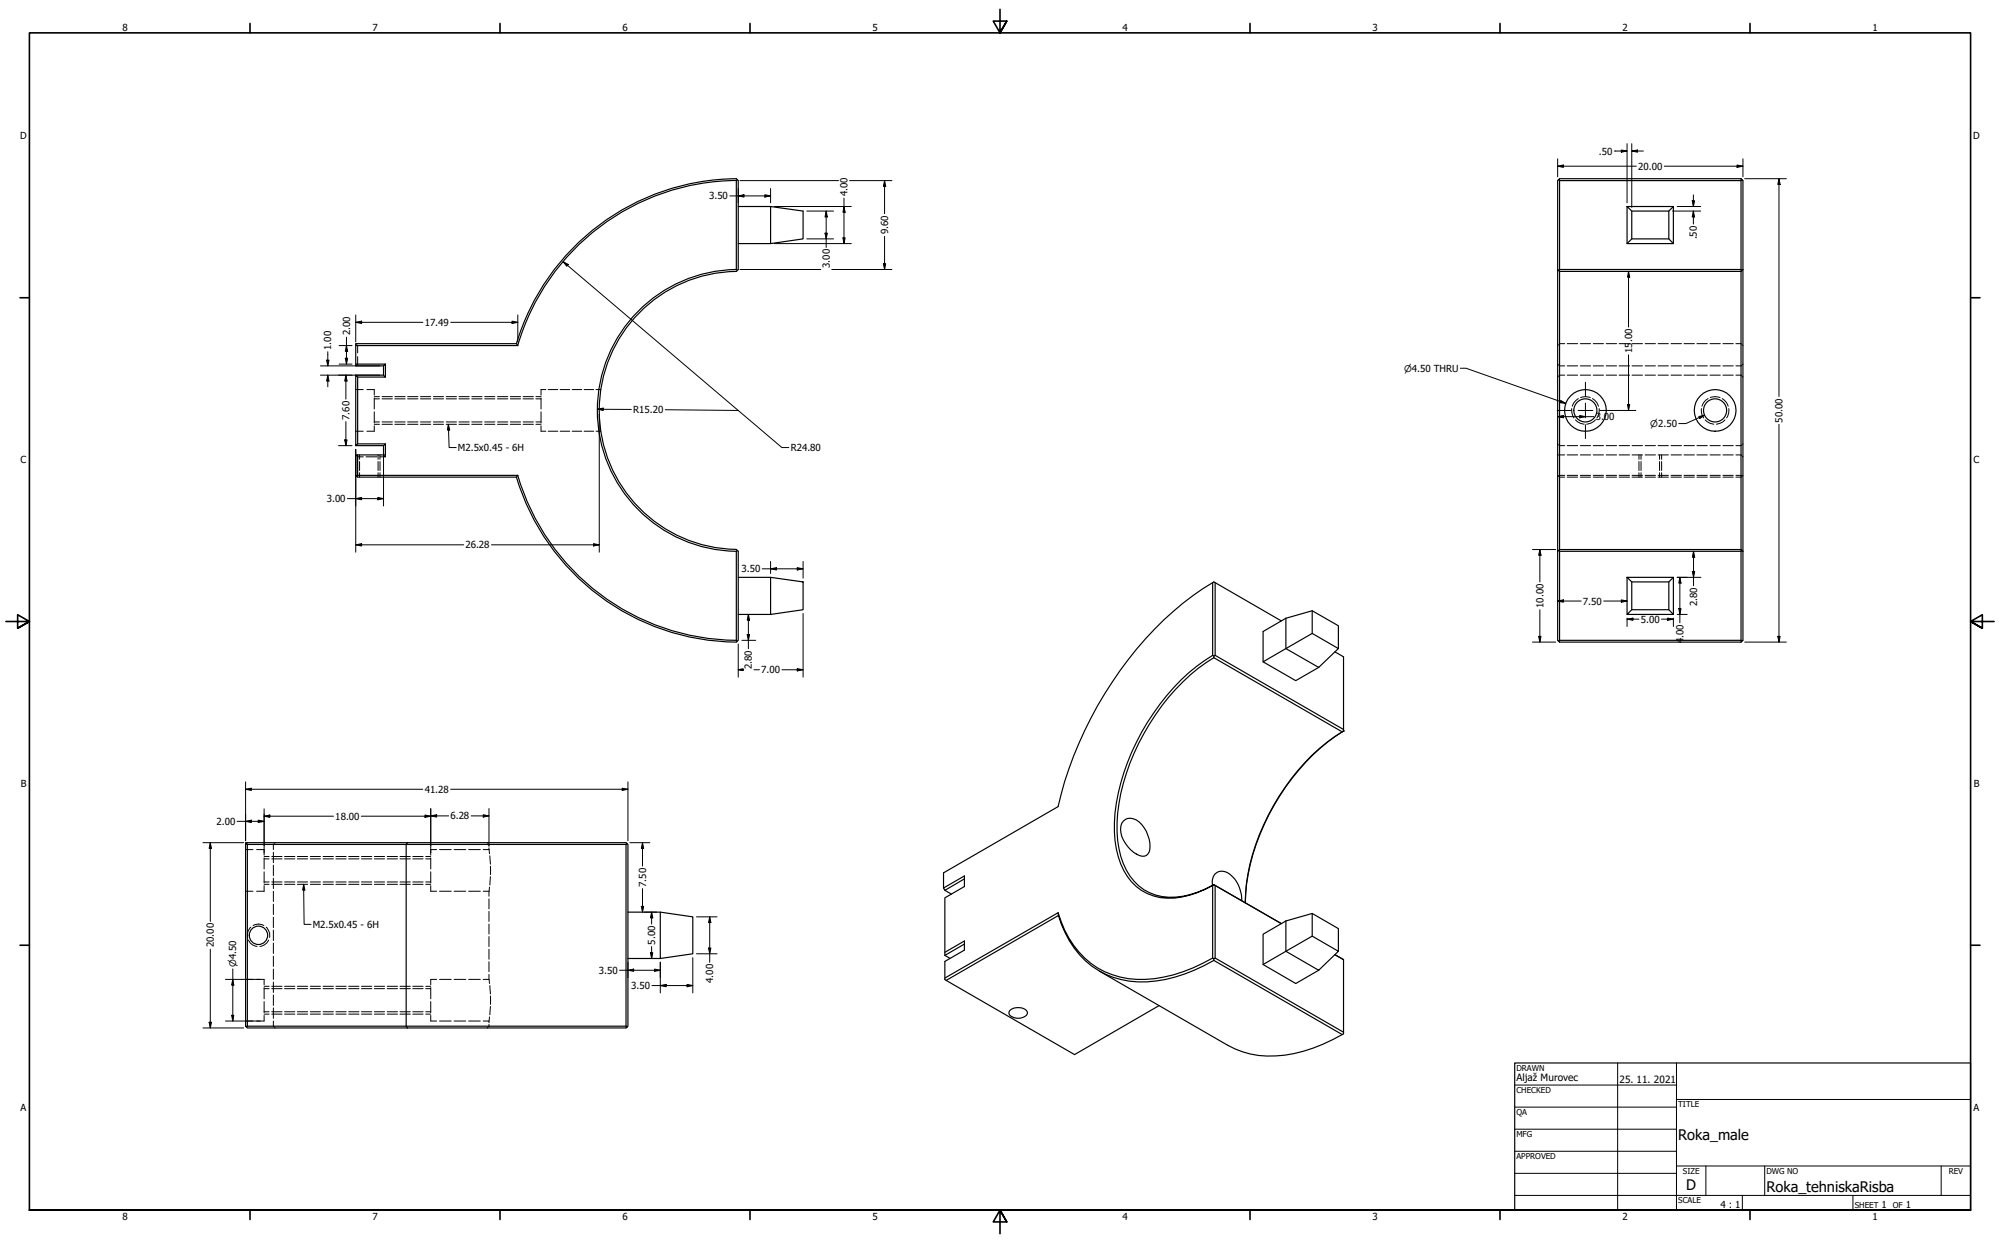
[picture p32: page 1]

D RA W N Alj a å M u r o v e c | 2 5 . 1 1 . 2 0 2 1

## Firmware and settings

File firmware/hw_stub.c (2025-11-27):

#include <stdio.h>
#include <stdint.h>
#include <stdbool.h>
#include <time.h>

// -----------------------------------------------------------------------------
// This file is a *stub* hardware layer for the vegetable harvester tool.
//
// It lets you compile and "run" the controller on a normal PC without any
// STM32/HAL code. All functions just print what they would do.
//
// On the real robot, you will replace the contents of these functions with
// actual GPIO / timer / UART code for the STM32L476 + MP6619 drivers.
// -----------------------------------------------------------------------------

// These enums must match the ones in tool_controller.c
typedef enum {
    MOTOR_GRIPPER = 0,   // Motor that opens/closes the cage
    MOTOR_VERTICAL = 1,  // Motor that moves the mechanism up/down
    MOTOR_AUX = 2,       // Spare / future motor
    MOTOR_COUNT
} MotorId;

typedef enum {
    MOTOR_DIR_STOP = 0,
    MOTOR_DIR_FORWARD = 1,
    MOTOR_DIR_REVERSE = 2
} MotorDirection;

// Simple internal flags for simulation
static bool status_led_on       = false;
static bool emergency_stop_flag = false;
static bool start_signal_state  = true;   // simulate "start" pressed once

// -----------------------------------------------------------------------------
// Initialization
// -----------------------------------------------------------------------------

void hw_init(void)
{
    // On STM32: init clocks, GPIOs, timers, UART, etc.
    // In stub: just print a message.
    printf("[HW] init()\n");
}

// -----------------------------------------------------------------------------
// Motor control
// -----------------------------------------------------------------------------

void hw_motor_set(MotorId id, MotorDirection dir, uint8_t duty_percent)
{
    const char *motor_name = "UNKNOWN";
    const char *dir_name   = "STOP";

    switch (id) {
        case MOTOR_GRIPPER:  motor_name = "GRIPPER";  break;
        case MOTOR_VERTICAL: motor_name = "VERTICAL"; break;
        case MOTOR_AUX:      motor_name = "AUX";      break;
        default:             motor_name = "INVALID";  break;
    }

    switch (dir) {
        case MOTOR_DIR_FORWARD: dir_name = "FWD";  break;
        case MOTOR_DIR_REVERSE: dir_name = "REV";  break;
        case MOTOR_DIR_STOP:    dir_name = "STOP"; break;
        default:                dir_name = "???";  break;
    }

    if (duty_percent > 100U) {
        duty_percent = 100U;
    }

    printf("[HW] motor %-8s dir=%-4s duty=%3u%%\n",
           motor_name, dir_name, duty_percent);

    // On STM32: here you would set GPIO direction pins and PWM duty.
}

void hw_motor_brake(MotorId id)
{
    const char *motor_name = "UNKNOWN";

    switch (id) {
        case MOTOR_GRIPPER:  motor_name = "GRIPPER";  break;
        case MOTOR_VERTICAL: motor_name = "VERTICAL"; break;
        case MOTOR_AUX:      motor_name = "AUX";      break;
        default:             motor_name = "INVALID";  break;
    }

    printf("[HW] motor %-8s BRAKE\n", motor_name);

    // On STM32: here you would disable EN or apply a braking configuration.
}

// Optional encoder read (not used yet, returns 0)
uint32_t hw_encoder_get(MotorId id)
{
    (void)id;  // unused in stub
    return 0U;
}

// -----------------------------------------------------------------------------
// Timing
// -----------------------------------------------------------------------------

// Very crude blocking delay using CPU time.
// Good enough for simulation; on STM32 you would use HAL_Delay or a timer.
void hw_delay_ms(uint32_t ms)
{
    const clock_t start = clock();
    const double target_seconds = (double)ms / 1000.0;

    for (;;) {
        const clock_t now = clock();
        const double elapsed = (double)(now - start) / (double)CLOCKS_PER_SEC;
        if (elapsed >= target_seconds) {
            break;
        }
    }
}

// -----------------------------------------------------------------------------
// Inputs: start + emergency stop
// -----------------------------------------------------------------------------

bool hw_start_signal(void)
{
    // In real hardware: read a GPIO or command from the main robot.
    // Stub: simulate a single rising edge at program start.
    if (start_signal_state) {
        start_signal_state = false;
        return true;
    }
    return false;
}

bool hw_emergency_stop_signal(void)
{
    // In real hardware: read an E-stop button / safety input.
    // Stub: always false unless you decide to toggle emergency_stop_flag in code.
    return emergency_stop_flag;
}

// -----------------------------------------------------------------------------
// Outputs: LED + debug text
// -----------------------------------------------------------------------------

void hw_set_status_led(bool on)
{
    status_led_on = on;
    printf("[HW] LED %s\n", status_led_on ? "ON" : "OFF");

    // On STM32: drive a GPIO here.
}

void hw_send_status(const char *text)
{
    if (text != NULL) {
        fputs(text, stdout);
    }

    // On STM32: send via UART, CAN, etc.
}

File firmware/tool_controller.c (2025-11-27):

#include <stdint.h>
#include <stdbool.h>

// -----------------------------------------------------------------------------
// Motor and direction definitions
// -----------------------------------------------------------------------------

typedef enum {
    MOTOR_GRIPPER = 0,   // Motor that opens/closes the cage
    MOTOR_VERTICAL = 1,  // Motor that moves the mechanism up/down
    MOTOR_AUX = 2,       // Spare / future motor (currently unused)
    MOTOR_COUNT
} MotorId;

typedef enum {
    MOTOR_DIR_STOP = 0,
    MOTOR_DIR_FORWARD = 1,
    MOTOR_DIR_REVERSE = 2
} MotorDirection;

// Semantic direction mapping — adjust FORWARD/REVERSE if wiring is flipped
#define GRIPPER_DIR_OPEN   MOTOR_DIR_FORWARD
#define GRIPPER_DIR_CLOSE  MOTOR_DIR_REVERSE
#define VERTICAL_DIR_DOWN  MOTOR_DIR_FORWARD
#define VERTICAL_DIR_UP    MOTOR_DIR_REVERSE

// -----------------------------------------------------------------------------
// Hardware abstraction layer (to be implemented on STM32)
// -----------------------------------------------------------------------------

// Initialize clocks, GPIO, timers, UART, etc.
void hw_init(void);

// Drive a motor with a given direction and duty (0–100% PWM).
void hw_motor_set(MotorId id, MotorDirection dir, uint8_t duty_percent);

// Actively brake / stop a motor.
void hw_motor_brake(MotorId id);

// Optional: read encoder position for a given motor (if encoders are used).
uint32_t hw_encoder_get(MotorId id);

// Millisecond delay (blocking).
void hw_delay_ms(uint32_t ms);

// Start signal (button or command from robot).
bool hw_start_signal(void);

// Emergency stop input (active when true).
bool hw_emergency_stop_signal(void);

// Status LED control.
void hw_set_status_led(bool on);

// Send debug / status text (e.g. UART).
void hw_send_status(const char *text);

// -----------------------------------------------------------------------------
// Tool parameters (prototype-friendly, tune later on hardware)
// -----------------------------------------------------------------------------

enum {
    TOOL_OPEN_GRIPPER_TIME_MS   = 800,   // time to fully open gripper
    TOOL_CLOSE_GRIPPER_TIME_MS  = 900,   // time to fully close gripper
    TOOL_MOVE_DOWN_TIME_MS      = 1200,  // time to move down for cut
    TOOL_MOVE_UP_TIME_MS        = 900,   // time to retract
    TOOL_SETTLE_TIME_MS         = 150,   // pause to let mechanics settle
    TOOL_INTER_CYCLE_DELAY_MS   = 250    // delay between cycles
};

enum {
    TOOL_SPEED_GRIPPER  = 60,  // % PWM
    TOOL_SPEED_VERTICAL = 70   // % PWM
};

// -----------------------------------------------------------------------------
// Internal helpers
// -----------------------------------------------------------------------------

// Run one motor for a given time, checking emergency stop regularly.
static void run_motor_for_time(MotorId id,
                               MotorDirection dir,
                               uint8_t duty_percent,
                               uint32_t time_ms)
{
    const uint32_t step_ms = 10; // how often we check E-stop
    uint32_t elapsed = 0;

    if (duty_percent > 100) {
        duty_percent = 100;
    }

    hw_motor_set(id, dir, duty_percent);

    while (elapsed < time_ms) {
        if (hw_emergency_stop_signal()) {
            // Immediate stop of all motion
            hw_motor_brake(MOTOR_GRIPPER);
            hw_motor_brake(MOTOR_VERTICAL);
            hw_motor_brake(MOTOR_AUX);
            hw_send_status("EMERGENCY STOP\n");
            return;
        }
        hw_delay_ms(step_ms);
        elapsed += step_ms;
    }

    hw_motor_brake(id);
}

// -----------------------------------------------------------------------------
// High-level tool behaviour
// -----------------------------------------------------------------------------

// One harvest cycle:
//
//  1) Open gripper (ensure it’s open)
//  2) Close gripper (grip stem)
//  3) Move down (mechanical cut happens at correct height)
//  4) Move up (retract)
//  5) Open gripper (release cut vegetable)
void tool_run_single_harvest_cycle(void)
{
    hw_send_status("[Tool] Harvest cycle START\n");
    hw_set_status_led(true);

    // 1) Open gripper fully
    hw_send_status("[Tool] Opening gripper\n");
    run_motor_for_time(MOTOR_GRIPPER,
                       GRIPPER_DIR_OPEN,
                       TOOL_SPEED_GRIPPER,
                       TOOL_OPEN_GRIPPER_TIME_MS);
    hw_delay_ms(TOOL_SETTLE_TIME_MS);

    // 2) Close gripper to grip the stem
    hw_send_status("[Tool] Closing gripper\n");
    run_motor_for_time(MOTOR_GRIPPER,
                       GRIPPER_DIR_CLOSE,
                       TOOL_SPEED_GRIPPER,
                       TOOL_CLOSE_GRIPPER_TIME_MS);
    hw_delay_ms(TOOL_SETTLE_TIME_MS);

    // 3) Move down to trigger the passive cutting mechanism
    hw_send_status("[Tool] Moving down for cut\n");
    run_motor_for_time(MOTOR_VERTICAL,
                       VERTICAL_DIR_DOWN,
                       TOOL_SPEED_VERTICAL,
                       TOOL_MOVE_DOWN_TIME_MS);
    hw_delay_ms(TOOL_SETTLE_TIME_MS);

    // 4) Move back up
    hw_send_status("[Tool] Moving up / retract\n");
    run_motor_for_time(MOTOR_VERTICAL,
                       VERTICAL_DIR_UP,
                       TOOL_SPEED_VERTICAL,
                       TOOL_MOVE_UP_TIME_MS);
    hw_delay_ms(TOOL_SETTLE_TIME_MS);

    // 5) Open gripper to release the cut stem
    hw_send_status("[Tool] Releasing gripper\n");
    run_motor_for_time(MOTOR_GRIPPER,
                       GRIPPER_DIR_OPEN,
                       TOOL_SPEED_GRIPPER,
                       TOOL_OPEN_GRIPPER_TIME_MS);

    hw_set_status_led(false);
    hw_send_status("[Tool] Harvest cycle END\n");
}

// Put tool in safe state immediately.
void tool_emergency_stop(void)
{
    hw_motor_brake(MOTOR_GRIPPER);
    hw_motor_brake(MOTOR_VERTICAL);
    hw_motor_brake(MOTOR_AUX);

    hw_set_status_led(false);
    hw_send_status("[Tool] EMERGENCY STOP triggered\n");
}

// -----------------------------------------------------------------------------
// Minimal blocking main loop for prototype testing
// -----------------------------------------------------------------------------

int main(void)
{
    hw_init();

    hw_send_status("[Tool] Vegetable harvester tool controller ready\n");

    bool previous_start_state = false;

    while (1) {
        bool start = hw_start_signal();

        // Emergency stop handling
        if (hw_emergency_stop_signal()) {
            tool_emergency_stop();
            // Stay here until E-stop is released
            while (hw_emergency_stop_signal()) {
                hw_delay_ms(10);
            }
        }

        // Rising edge on start signal triggers one harvest cycle
        if (start && !previous_start_state) {
            tool_run_single_harvest_cycle();
            hw_delay_ms(TOOL_INTER_CYCLE_DELAY_MS);
        }

        previous_start_state = start;
        hw_delay_ms(10);
    }
}

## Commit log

2025-11-27 Added prototype control code
2025-11-27 Added prototype simulation code
